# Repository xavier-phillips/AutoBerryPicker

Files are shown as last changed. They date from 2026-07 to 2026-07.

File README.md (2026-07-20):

<div align="center">

# AutoBerryPicker

**An autonomous, low-cost robotic arm that optically detects and picks strawberries, built as a VCE Systems Engineering Unit 3 & 4 folio project.**

Xavier Phillips, Viewbank College

  

   

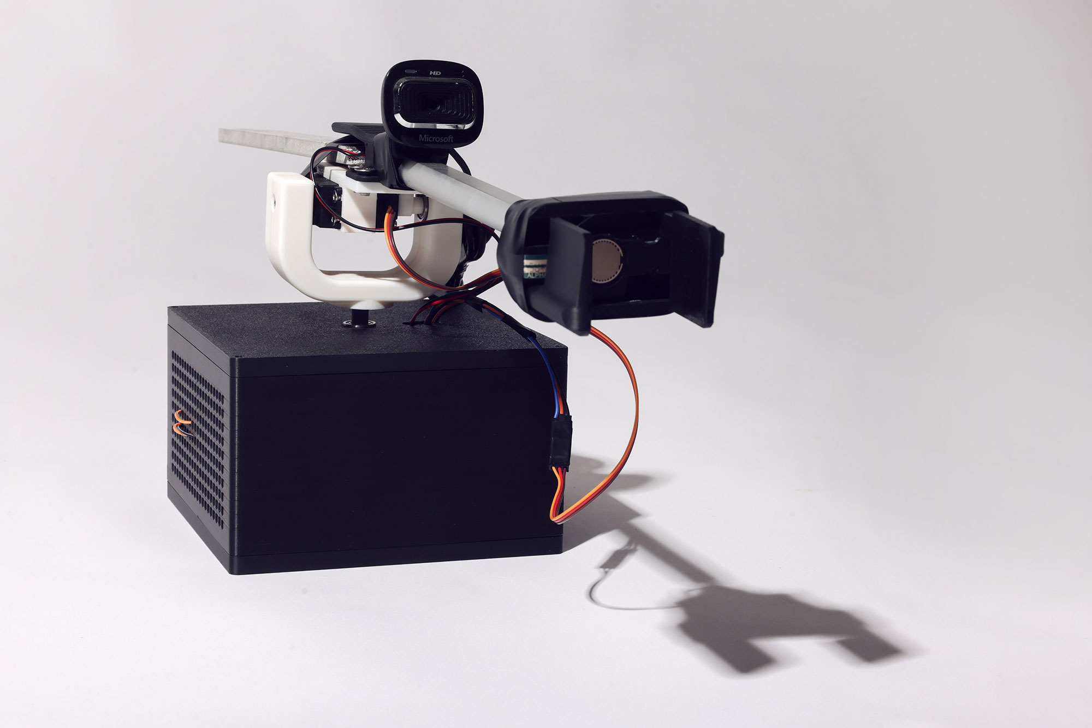
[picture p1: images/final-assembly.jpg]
Completed AutoBerryPicker assembly

_The completed AutoBerryPicker device. Top Designs 2026 / Source: Courtesy of the Victorian Curriculum and Assessment Authority. / Photo: Nicole Cleary_

</div>

---

## Contents

- [Overview](#overview)
- [Project Snapshot](#project-snapshot)
- [Technical Skills](#technical-skills)
- [Design Brief](#design-brief)
- [Design Process](#design-process)
- [Planning](#planning)
- [Development Log](#development-log)
- [Testing & Results](#testing--results)
- [Evaluation & Improvements](#evaluation--improvements)
- [Reflection](#reflection)
- [Gallery](#gallery)
- [Documentation](#documentation)
- [Acknowledgements & License](#acknowledgements--license)

---

## Overview

I built this robotic arm for my VCE Systems Engineering project to explore automation in agriculture, inspired by the United Nations' Sustainable Development Goal (SDG) #8: "Decent Work and Economic Growth". Specifically, Target 8.7 aims to eradicate forced labour and end modern slavery, including child labour.

[Statistics indicate](https://www.dol.gov/agencies/ilab/resources/reports/child-labor/findings) that the most common industry exploiting child and forced labour is the agricultural sector, where laborers are often used to pick small crops like cotton and berries.

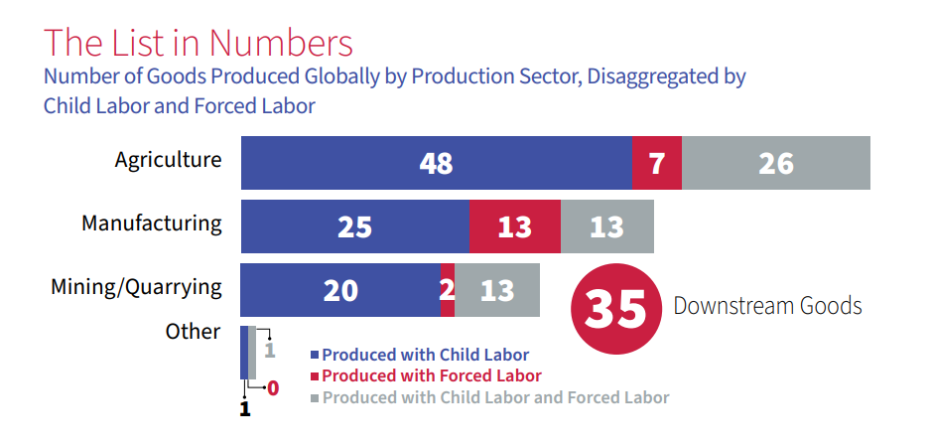
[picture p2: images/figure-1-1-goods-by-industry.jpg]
Proportion of goods produced by children and forced labour by industry

_Proportion of goods produced by children and forced labour by industry._

The issue can be alleviated by implementing automated robotic arms in farming areas. By creating an affordable robotic arm that can optically detect crops and carefully remove them from plants, such devices could replace children and forced labourers without reducing crop yield or efficiency. Food wastage may also be reduced by reducing the amount of bruised or damaged crops due to mishandling, thus supporting the UN's SDG 12.

The project design process utilised CAD software (Onshape) to precisely design components, fabricated with 3D printing additive manufacturing technology. The electromechanical system features an optical camera sensor and a custom program to identify strawberries in real-time and record their position; a microcontroller and motor controller relay this position to a robotic arm, which moves to the strawberry and precisely grips and removes the crop from the plant.

The project focuses on picking strawberries specifically, as they are fragile berries that can be used to demonstrate the robotic arm's ability to pick delicate crops precisely, without bruising them. If the device is capable of picking strawberries, it can be easily adapted to pick other crops, such as other types of berries or even cotton.

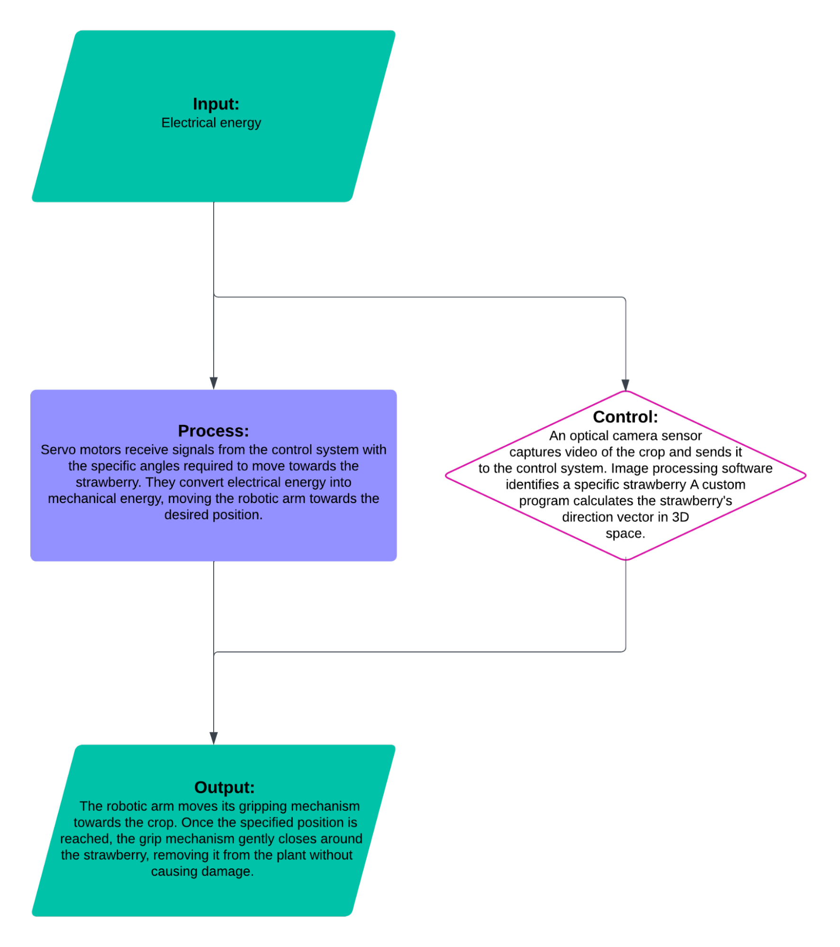
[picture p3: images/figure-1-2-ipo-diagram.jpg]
IPO diagram of the AutoBerryPicker device

_IPO diagram of the features of the AutoBerryPicker device._

<details>
<summary><strong>Glossary</strong></summary>

| Term | Meaning |
| --- | --- |
| **Device** | The complete, functioning electromechanical system |
| **User** | An individual or organisation implementing the device in a farm, workplace, or other agricultural setting |
| **FSR** | Force-sensing resistor |

</details>

---

## Project Snapshot

### Details

| | |
| --- | --- |
| **Course** | VCAA Systems Engineering, Units 3 & 4 (2025) |
| **Institution** | Viewbank College |
| **Developer** | Xavier Phillips |
| **Timeline** | 15-week development cycle |
| **Budget** | \$150 AUD |
| **Final Score** | 29/40 (73%) |
| **Core stack** | Onshape (CAD); Arduino IDE; Python (OpenCV, NumPy); Raspberry Pi 3; Arduino Uno R3 |
| **Manufacturing** | FDM 3D printing (Bambu Lab P1S / X1C); CNC laser engraving |

### Specifications

| Spec | Value |
| --- | --- |
| Degrees of freedom | 3 (polar/spherical configuration) |
| Power supply | 12V DC (battery or mains-rectified) |
| Max. power draw (theoretical) | 41.2 W |
| Weight (excl. power source) | 1081.4 g measured (976 g expected)  |
| Strawberry recognition accuracy | 0% false positives (16 trials) |
| Measured picking rate | 2.1 picks/min |
| Measured arm movement time | 2.07 s ± 0.13 s |

---

## Technical Skills

| Area | Skills and tools |
| --- | --- |
| Mechanical design | CAD modelling and mechanical design in Onshape |
| Embedded systems | Arduino Uno R3, Arduino IDE, embedded programming |
| Computer vision | Python, OpenCV, NumPy, real-time strawberry detection |
| Digital fabrication  | FDM 3D printing, CNC laser engraving |
| Electronics | Circuit design, power and current calculations, soldering, wiring, heat-shrink insulation |
| Testing and analysis | Diagnostic testing, statistical analysis, confidence intervals, two-tailed significance testing |
| Project management | Risk assessment, OH&S documentation, Gantt charts, timeline planning |
| Documentation | Technical documentation and evidence-based design evaluation |

<details>
<summary>Technical details</summary>

- Designed and modelled mechanical components using Onshape CAD.
- Programmed an Arduino Uno R3 using the Arduino IDE for embedded system control.
- Developed a computer vision system using Python, OpenCV, and NumPy for real-time strawberry detection.
- Manufactured prototypes using FDM 3D printing (Bambu Lab P1S and X1C) and CNC laser engraving.
- Designed and assembled electronic circuits, including power and current calculations, soldering, wiring, and heat-shrink insulation.
- Developed diagnostic tests and analysed results using statistical methods, including confidence intervals and two-tailed significance testing.
- Managed project planning through risk assessments, OH&S documentation, Gantt charts, and timeline tracking.
- Produced technical documentation and evaluated the final design using evidence-based analysis.

</details>

---

## Design Brief

The project's goal, an affordable electromechanical system to reduce worldwide reliance on unethical labour practices for crop harvesting, was governed by a strict set of constraints:

| Constraint | Why It Matters |
| --- | --- |
| Budget limited to **$150** | Ensures the device is affordable, as the cost of the final product influences its potential as a valid replacement for child labour and forced labour in the agriculture industry |
| Single developer | Limits complexity; simplicity must be prioritised to ensure realistic completion |
| **12V DC** power supply or battery | Ensures flexibility in where and how the device is used |
| Weight (excl. power source) **< 5 kg** | Ensures portability and compatibility with many mounting systems, including moving vehicles |
| Pick **≥ 5 strawberries/minute** | Based on the average weight of [12-15kg of strawberries picked per hour by workers](https://wikifarmer.com/); assuming 4 robots replace 1 human worker, a required picking rate of 5 per minute was determined |
| Max power draw of **24 watts** | Improves compatibility with mobile power sources such as a common 12V 2A portable battery |
| No safety risk to nearby individuals, users, or the environment | All moving parts and circuits must be enclosed to prevent accidental injuries from the mechanism or electrical shock |

<details>
<summary><strong>Full arm, control system & grip mechanism requirements</strong></summary>

**The robotic arm must:**

- Have three degrees of freedom, allowing it to move to any position in 3D space within a predetermined spherical radius while its base is in a fixed position
- Have a spherical range radius large enough to reach more than one plant without moving the base
- Have motors with sufficient torque to support the mechanism itself, and any additional load exerted when picking the crops
- Have motors with an appropriate RPM and acceleration to allow the picking of several strawberries per minute
- Have a base which can be secured easily with bolts or screws, allowing it to be mounted wherever the user desires
- Have a sturdy construction using a light material, and a full plastic shell to enclose wiring

**The control system must:**

- Have the capability to recognise strawberries in real-time
- Be able to extrapolate or estimate the relative position of a strawberry in 3D space based on a video camera feed and other sensors, in real-time
- Be able to calculate the angles of the servo motors to reach the desired 3D position to pick a strawberry, in real time
- Be compatible with open-source platforms such as Arduino IDE and Python

**The grip mechanism must:**

- Be able to evenly apply force to remove a strawberry from a strawberry plant without any bruising
- Be able to remove strawberries from strawberry plants, using as much force as required

</details>

<details>
<summary><strong>Design considerations explored</strong></summary>

- Increasing battery life using renewable energy sources like solar panels, adhering to Cradle to Cradle (C2C) standards
- Sustainably sourced materials that adhere to C2C standards
- The ability to manually select which crop the device should pick
- A trough for depositing picked crops into, separated based on crop type
- A secondary grip mechanism to hold onto the stalk while the crop is picked
- A modular belt conveyor system to transport harvested materials to an industrial storage area
- Wheels or tracks to provide an additional two degrees of freedom
- Remote monitoring and control via radio signals, Bluetooth, or Wi-Fi
- Regenerative braking circuits for the servo motors to reduce net energy consumption
- A user-friendly web or mobile interface for configuration of settings
- Easily accessible and replaceable internal/external components, requiring no specialised tools
- A manual or set of guidelines to help users operate the device

</details>

---

## Design Process

### Benchmarking Against Similar Products

| Product | Similarities | Differences |
| --- | --- | --- |
| Large robotic arm for vertical commercial strawberry farms (StrawberryPlants.org, 2023) | Articulated robotic arm; 2-finger robotic grip; only picks ripe crops; picks crops from a bottom-up angle | Optimised for vertical farms; primarily metal-based; moves autonomously using wheels; linear movement to pick crops |
| Large fixed robotic arm for cotton picking (Green Robot Machinery, 2022) | Optimised for traditional farms | Spherical robotic arm; only picks cotton using a vacuum; primarily metal-based; fixed base; picks from a top-down angle |
| Automatic strawberry picker (Octinion, 2017) | Articulated robotic arm; 2-finger robotic grip; only picks ripe crops; uses rotational movement; grips using a large surface area (cupped grip); picks from bottom-up angle | Optimised for vertical farms; automatically sorts bruised/diseased crops; primarily metal-based; moves autonomously using wheels |
| Cotton-harvesting autonomous platform (Maja et al., 2021) | Optimised for traditional farms; 2-finger robotic grip; uses linear movement | Cartesian robotic arm; only picks cotton; primarily metal-based; moves autonomously using wheels; picks from top-down angle; relies on pre-programmed map route and GPS |

_Overall summary of observations from research of various similar products._

The Octinion strawberry picker brought useful inspiration for how to carefully remove delicate crops from plants without bruising or damaging the crop. The device uses a rotating motion to remove strawberries and hold them in a cup-shaped holder, and the large surface area of the holder minimises pressure on the strawberry, reducing the risk of bruising and damage.

### Robotic Arm Type Selection

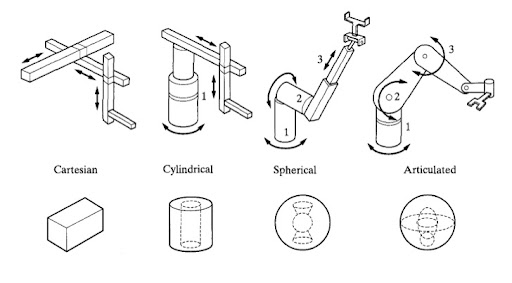
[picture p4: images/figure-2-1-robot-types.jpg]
Illustration of the 4 main robot types evaluated

_Illustration of the 4 main robot types that were evaluated._

| Type | Verdict |
| --- | --- |
| Cartesian Robot | Offers high precision and rapid acceleration but lacks range, requiring far more materials and larger size; deemed unsuitable |
| Cylindrical Robot | Simple coordinate system and construction, cheap and easy to program, but lacks flexibility for delicate, organic shapes; deemed unsuitable |
| **Polar (Spherical) Robot** | Uses a rotary actuator for elevation and a single linear actuator as the final degree of freedom that extends and retracts. **Selected.** |
| Articulated Robot | Can approach a point from various angles and navigate hard-to-reach areas, but requires more complex 3D position determination; considered but not selected |

> **Selected design rationale:** the polar robot approach was selected, as it offers sufficient range and flexibility while having a lower cost, software complexity, and hardware complexity. The control subsystem maps each camera pixel to a direction vector, and the device aligns itself in the rotational (base) axis and the elevational axis to point towards a direction vector at the centre of a crop. The radial (extension) axis extends using a linear actuator until it reaches a crop, using a button or touch sensor to detect contact. Once reached, the grip mechanism performs a grip action, and the radial axis retracts, removing the crop from the plant.

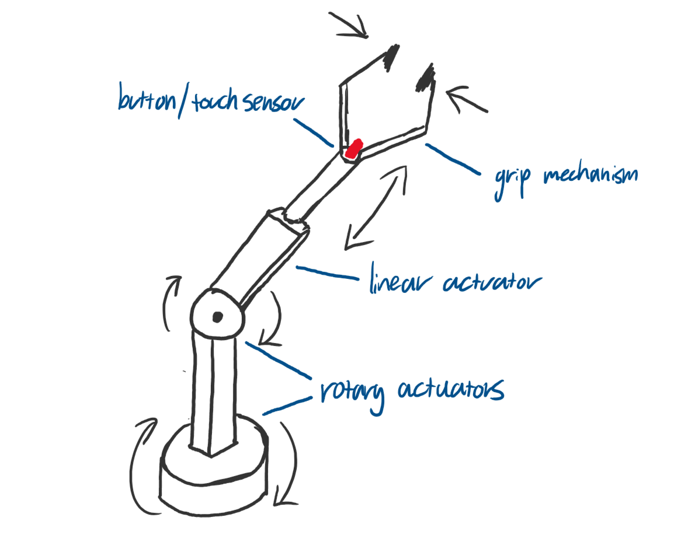
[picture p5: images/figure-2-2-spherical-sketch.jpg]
Sketch of the device in spherical configuration

_Sketch of the device in spherical configuration, including the three potential movement axes, and the touch sensor on the grip mechanism._

### Actuation, Sensing & Materials

<details open>
<summary><strong>Motor & actuator selection</strong></summary>

The DC electric linear actuator was selected over a servo linear actuator, primarily due to its cost-effectiveness, flexibility, and potential stroke length. Torque calculations for the elevational axis (modelled as a class 1 lever in Desmos, using a counterweight to counter gravity) informed the selection of MG996R servo motors for the rotational and elevational axes, providing adequate torque and precision for the lightweight configuration.

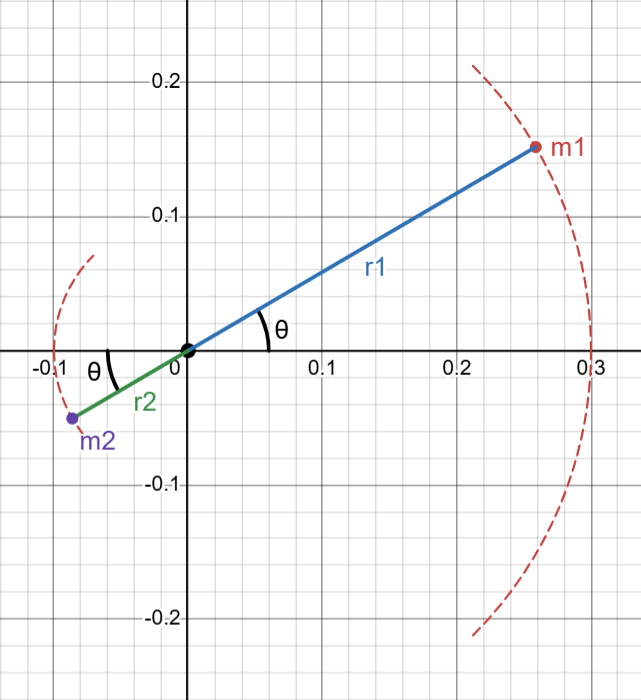
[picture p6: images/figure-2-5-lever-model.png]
Mathematical model of the arm as a 1st class lever

_Mathematical model of the arm as a 1st class lever in Desmos graphing calculator._

</details>

<details>
<summary><strong>Position determination & sensing</strong></summary>

A single camera and contact sensor setup was selected, rather than a complex stereoscopic system, reducing programming complexity and component cost while offering higher precision through direct physical feedback. The primary contact sensor is a Force-Sensing Resistor (FSR), chosen for its high sensitivity and low actuation force, ideal for detecting contact with a delicate strawberry. To prevent false positives from leaves, this is paired with a colour sensor with a built-in LED, helping to ensure the object is red and ripe before the grip sequence is initiated.

</details>

<details>
<summary><strong>Materials selection</strong></summary>

| Component | Options considered | Decision |
| --- | --- | --- |
| 3D printing filament | PLA vs Carbon Fibre Filament | **PLA**: cheaper for rapid prototyping and iteration, theoretically sufficient strength |
| Soft grip material | TPU flexible filament vs Sponge | **Sponge**: additional precision/durability not required for prototyping, easily cut and replaced |
| Base/frame | MDF panels vs alternatives | **MDF**: cheaper and easier to modify for mounting |

</details>

<details>
<summary><strong>Power & electronics</strong></summary>

A Raspberry Pi 3 performs real-time image analysis from the USB webcam, chosen for being compact and affordable while having sufficient processing power. It sends simple commands to an Arduino Uno R3, which serves as an intermediate controller for electronic components, while also sending FSR sensor and colour sensor data back to the Raspberry Pi. The Arduino was selected for being simple, reliable, and well-documented.

| Component | Max Current | Voltage | Power |
| --- | --- | --- | ----- |
| Colour sensor | 2mA | 5V | 10mW  |
| Linear actuator | 1A | 12V | 12W |
| MG996R (×2) | 2.5A | 5V | 12.5W |
| SG90 (grip) | 700mA | 5V | 3.5W  |
| Arduino Uno R3  | 50mA | 5V | 250mW |
| L298N | 36mA | 12V | 432mW |

_Maximum current, nominal voltage, and power draw of all electrical components._

In the worst-case scenario, the device draws a maximum of 41.2W, requiring the 12V power supply to supply at least 3.43A. Applying an industry-standard Factor of Safety of +125%, a requirement of 4.29A for the power supply was determined.

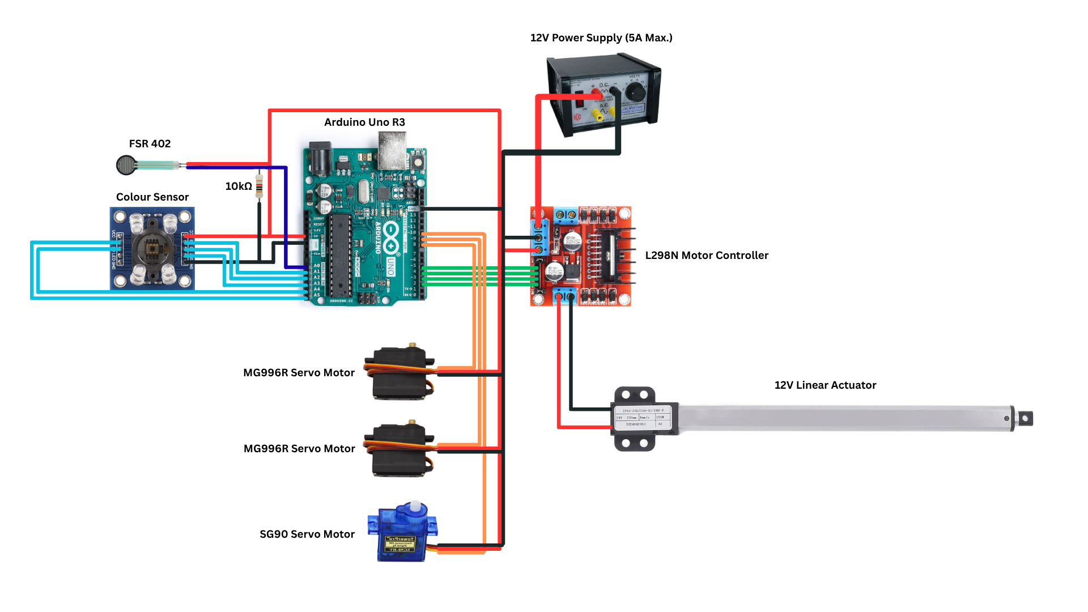
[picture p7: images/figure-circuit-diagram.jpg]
Circuit diagram of the AutoBerryPicker

_Figure: Circuit diagram of the AutoBerryPicker system._

</details>

### Final Design

The final design of the AutoBerryPicker balances range, flexibility, cost, and complexity. Because a heavy-duty linear actuator for the elevation axis would require torque far exceeding that of any affordable servo motors, I chose a lightweight 12V DC linear actuator for the extension axis. This enabled the use of MG996R servo motors for the rotational and elevational axes. Combined with a dual-sensor system, it formed an effective and affordable solution that met the original constraints.

---

## Planning

Tool and software selections were justified against alternatives:

| Tool / Software | Alternative(s) considered | Why it was chosen |
| --- | --- | --- |
| **Onshape** (CAD) | Autodesk Inventor | Cloud-based, automatic saving, allows work at school/home with no file transfer, infinite project history |
| **Arduino IDE** | PlatformIO | Simplicity, wide documentation, built-in example code snippets |
| **Python** (OpenCV, NumPy) | C++ | Simplicity and library availability: OpenCV for image processing/contour detection, NumPy for maths and GUI display |
| **VS Code** | Python IDLE, PyCharm | Efficient UX, multi-file project management, excellent debugging features |
| **3D printer** (Bambu Lab P1S & X1C) | CNC milling, manual fabrication | Custom/complex parts, precise small tolerances, high strength-to-weight ratio, fast printing enabled rapid, iterative prototyping |
| **CNC laser engraver** | 3D printing or ordering a base plate | High precision on 2D profiles, smoother/more accurate finish, higher speed |
| **Lego® bricks** | Cardboard mockups, skipping to CAD | Rapid, rough prototyping to test the mechanical idea of a polar robotic arm before investing time into CAD |
| **Electronics tools** (soldering iron, heat gun, hot melt glue gun) | Solderless breadboards, crimped connections | Reliable, durable electrical connections; reduced risk of failure due to tension on wires |
| **Diagnostic tools** (multimeter, DC power supply) | Guesswork, batteries for all testing | Essential for testing electronic components and finding faults |

A detailed work timeline plan, risk assessments, and a Gantt chart were completed to guide the 15-week production schedule.

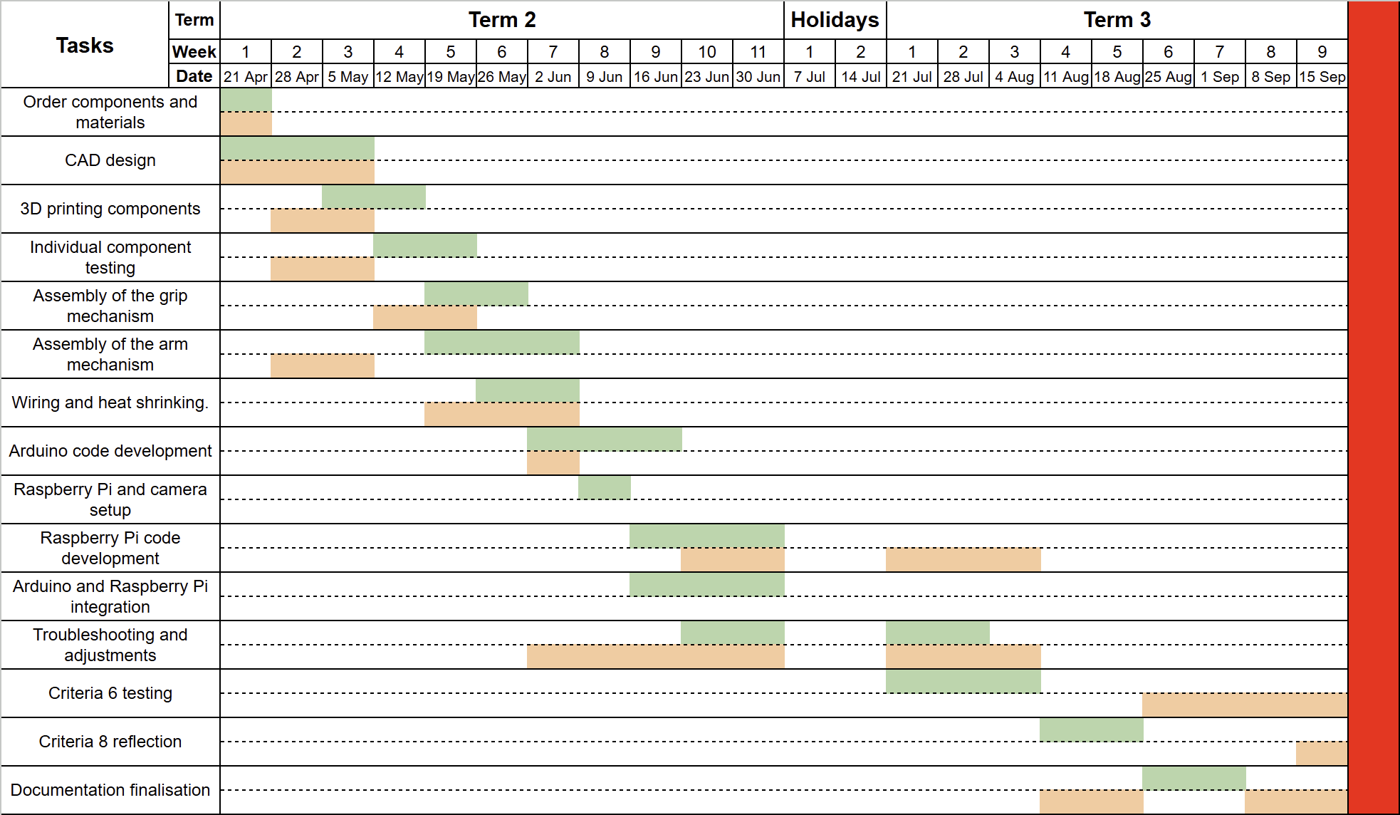
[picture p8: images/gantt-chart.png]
Gantt chart comparing planned vs actual timeline

_Planned (green) vs actual (orange) project timeline._

---

## Development Log

I developed the system over 15 weeks, following an iterative process where issues identified at the end of each session were addressed in the next. In Week 1, I built a rapid LEGO® prototype of the mechanical concept (base, rotational and elevational axes, linear axis, and grip mechanism) to gain a practical understanding of possible design challenges before committing to CAD and fabrication.

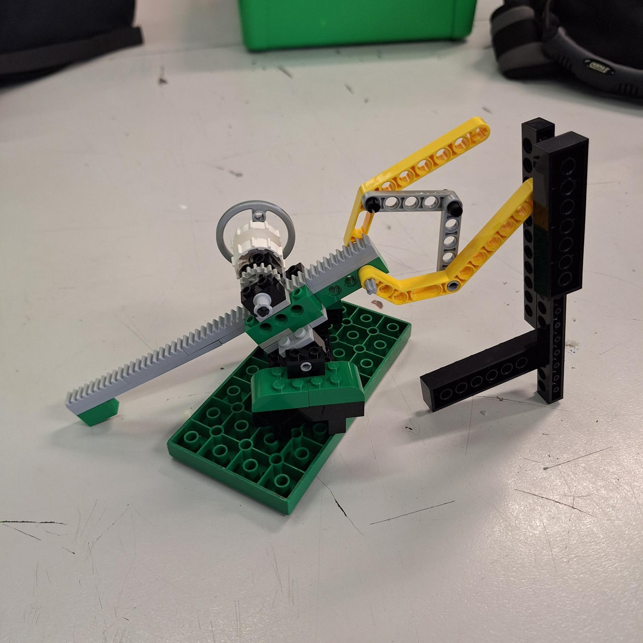
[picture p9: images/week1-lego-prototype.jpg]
LEGO prototype of the polar arm concept

_Early LEGO® prototype used to test the polar robotic arm concept._

The use of 3D printing technology was invaluable, allowing parts to be completely redesigned and reprinted within hours of identifying faults. Extensive daily logs documented the development, which proved useful for retrospectively clarifying past decisions and for evaluating repairability during later diagnostic testing.

> **Notable technical setbacks** encountered and resolved (or documented for future improvement) during the build:
>
> - A thin-walled central vertical shaft that snapped several times during development and was replaced, with friction ultimately proving insufficient to secure it to the rotational motor
> - A grip-mechanism load test in which the gears started to slip, leading to a critical failure and permanent damage to a servo motor from excessive torque load

| Week | Highlights |
| --- | --- |
| **1**  | Built a basic unpowered LEGO® prototype of the base, rotational and elevational axes, linear axis, and grip mechanism, to gain a practical understanding of possible challenges. Noted significant torque on the arm due to the weight of the grip mechanism and linear actuator, and realised it may be easier to have the entire motor move with the elevation mechanism, using the motor's own weight as a counterweight. Ordered components from Amazon and Core Electronics, sourced others from Viewbank College, and began CAD modelling of the circuit box in Onshape. |
| **2**  | The first iteration of the circuit box base was successful, with all parts and 3D printed standoffs fitting well. Found some flaws in the design and addressed them with hand tools and modifications in CAD. Successfully tested a new variation of the code with a draft polar coordinate system for easier control interfacing. |
| **3**  | The polar coordinate program test was successful, and test fitting gave a good demonstration of the range of the arm and showed the fit was secure. The main components of the arm were assembled without issue, and required components for the grip mechanism were sourced. |
| **4**  | With the majority of CAD work done, work moved to 3D printing the grip mechanism parts and assembling them. Became slightly behind schedule due to time spent catching up on documentation. Decided to use a pre-made gripper design (credit to Techniccontroller), and added a hole in the grip mechanism for a bolt to secure it to the linear actuator. |
| **5**  | With all electrical components in place, work began on finishing the wiring and closing the circuit box. The FSR was found to be functioning correctly. Heat-shrunk cable bundles and did cable management and soldering. |
| **6**  | Wiring and heat shrinking were completed, and the wiring pins of the motors were verified. Code and testing gave insights into how to program the arm to move, and verified that the motors and actuators in the arm work correctly. The circuit box was closed successfully with no issues, on track to begin software development: manual control first, then automatic optical detection with FSR feedback, before porting to the Raspberry Pi for full autonomy. |
| **7**  | Testing discovered critical flaws in the design along with hardware faults, including a damaged MG996R servo motor with sheared gears, which was removed for replacement. Redesigned the 3D printed components of the elevational axis to reduce loads and torques, including adding a counterweight, redesigned the actuator mount for improved strength, and redesigned the rotational base to be two-sided with an axle to improve strength and reduce flex. |
| **8**  | Progress on the new actuator mount and new MG996R motor allowed the elevation axis mechanism to be reassembled and testing resumed. Uncovered several issues with the modifications made to the rotational base and actuator mount, fixed them in CAD, and moved to a third iteration of both parts: filing counterweight pegs, reducing the elevational motor shaft diameter, strengthening axle supports, and adding an M3 bolt to secure the elevational motor. The rotating assembly was reassembled successfully with no apparent issues. |
| **9**  | Filed down the aluminium counterweight to allow it to fit. Completed the main mechanical and electrical components with no serious issues, and testing went well, manually moving the device into various positions and picking up and moving a foam block. Due to time constraints, decided to remove the FSR object-collision-detection feature and instead rely on strawberries being pushed along by the grip mechanism. |
| **10** | Implemented automated colour masking and boundary boxes for the detection of colours, laying the foundation of the software, and secured the counterweight and camera for more consistent performance. More progress than planned was made on user interface upgrades, and the program draft was ready for testing. Identified an issue with the Python GUI freezing, preventing progress towards automation. |
| **11** | A motor controller failure was only a minor setback: the cause of the actuator not moving was quickly identified and a replacement installed. Another minor setback with an unexpected modification was again quickly resolved. Decided to use a PID program as the guidance for the control subsystem, and gained a good grasp of the concept, with the next step being to create the OpenCV colour masking system to determine positional error. |
| **12** | Solid progress was made on an HSV Tuner program to find the optimal HSV settings for detecting red objects, which worked without issue and impressively distinguished red objects from the background, though detection failed at some angles when not directly lit. A wrap-around HSV system was trialled but ultimately showed no real improvement, so the design reverted to a simple HSV range, since strawberries are almost axially symmetrical and look similar from all angles. |
| **13** | Created a Red Foam Block to allow testing of the PID system. The main work on the PID code was completed, and a test of the new PID control program was successful, with the arm able to track moving red objects and centre itself on stationary ones. Decided to start with a PD controller first, excluding the Integral term and using only the x-axis, and made GUI updates for adjustable center sliders. |
| **14** | Added y-axis PID control to allow elevational movement. The new version with all axes implemented worked well and was able to successfully navigate to targets in 3D space, though oscillations were observed in the horizontal (rotational) axis. Testing of different PID settings provided valuable data on effective settings to reduce these oscillations and improve picking efficiency, precision, and accuracy. |
| **15** | Added a centroid calculation and smoothing filter, using a weighted moving average for the coordinates of objects, for more stable and reliable tracking with less jitter. Added a feature to save and load PID settings via a JSON file system. The final test of the device was completed, and it was decided not to use the Raspberry Pi 3, sticking with the laptop for running code instead due to time constraints, prioritising the functionality of the device. |

<details>
<summary>Development Photos</summary>

Week 1: LEGO prototype and circuit box CAD
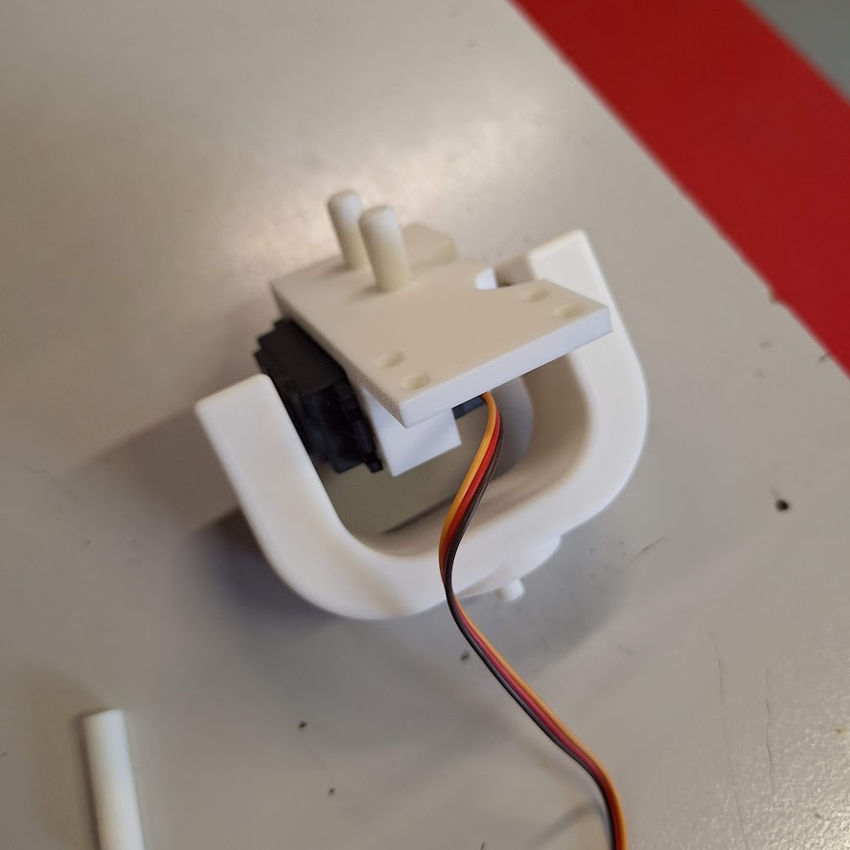
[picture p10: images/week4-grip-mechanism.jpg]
Week 4: grip mechanism assembly

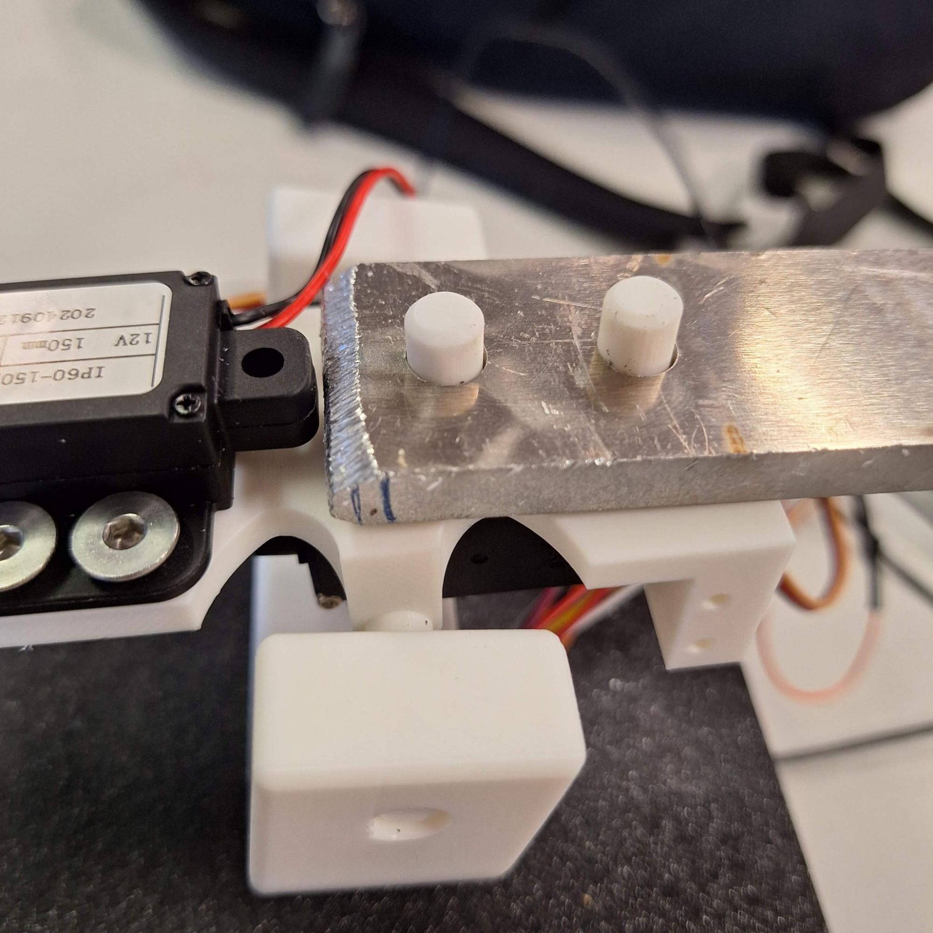
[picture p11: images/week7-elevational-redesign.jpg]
Week 7: redesigned elevational axis and counterweight

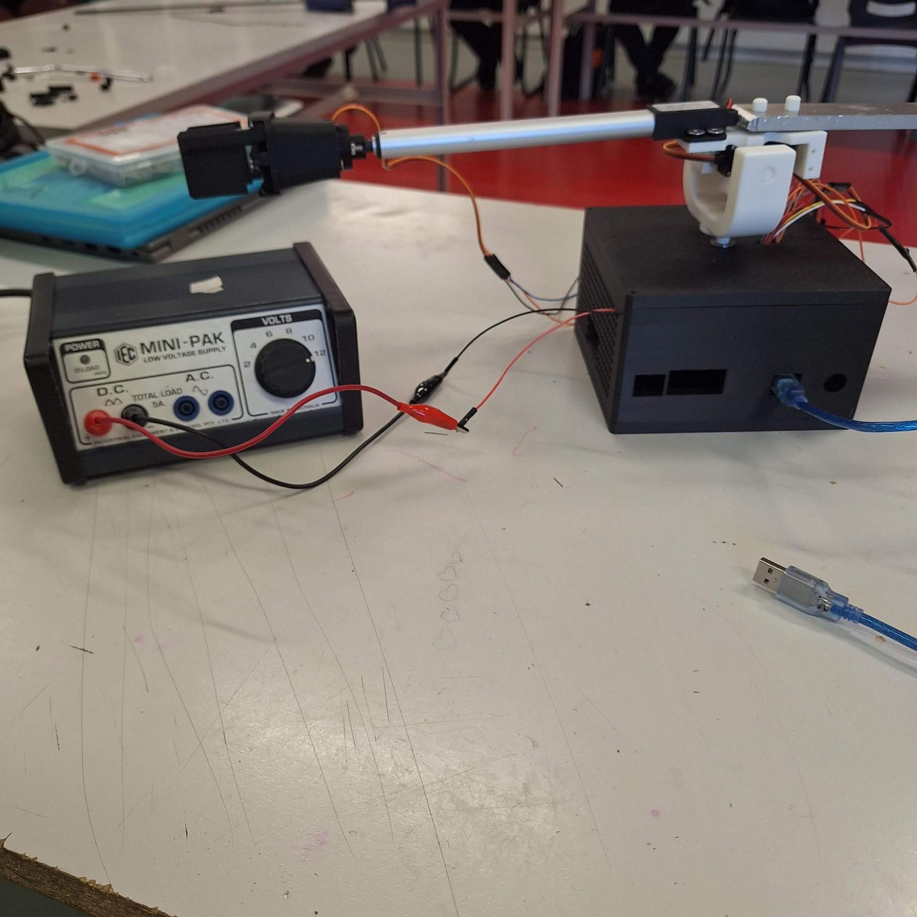
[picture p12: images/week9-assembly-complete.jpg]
Week 9: mechanical and electrical assembly complete

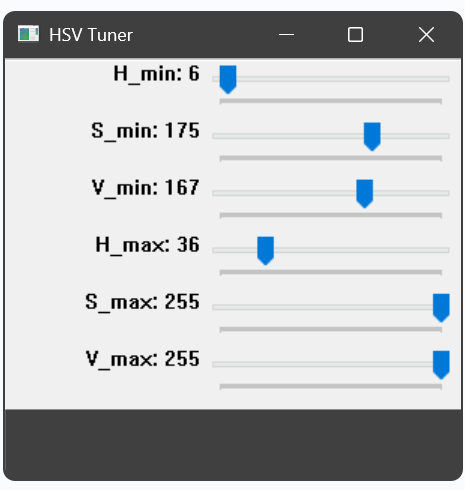
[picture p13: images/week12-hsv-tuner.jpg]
Week 12: HSV Tuner program in use

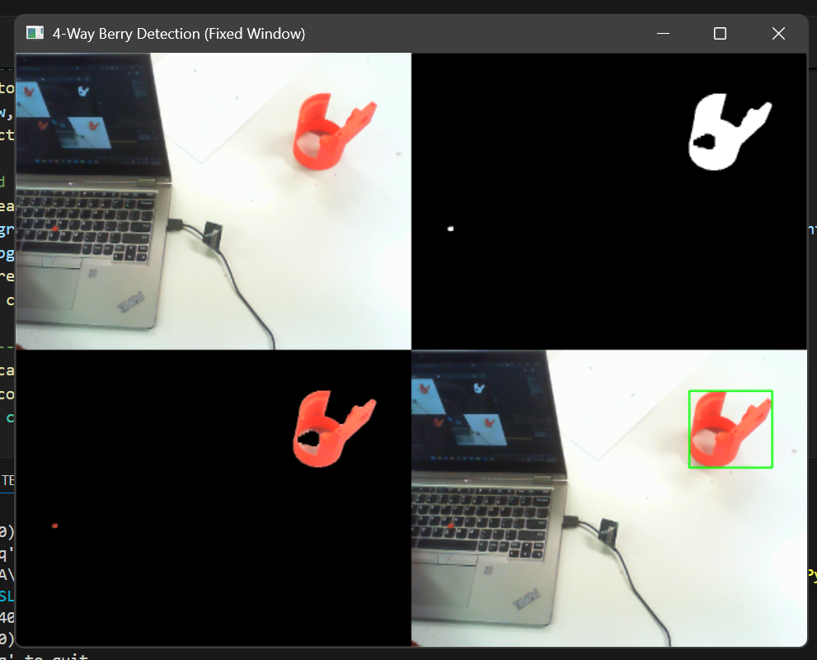
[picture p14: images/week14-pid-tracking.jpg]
Week 14: PID control tracking targets in 3D space


</details>

---

## Testing & Results

Ten diagnostic tests were conducted to evaluate the completed device against the design brief.

| # | Test | Aim | Result |
| --- | --- | --- | --- |
| 1 | Arm Range of Motion | Determine range of positions the arm can move to in 3D space | Rotational axis achieved only 52° (expected 180°, **-71%**), extension axis achieved 150mm (0.0% difference), elevational axis achieved 52° (+3.8%). Likely cause: poor attachment/skipping of the central vertical shaft |
| 2 | Arm Movement Speed | Determine time to move the arm between positions | Average of **2.07s** across 4 trials (95% CI: 1.94-2.20s), significantly less than the 3-second estimate |
| 3 | Torque and Stalls | Determine if MG996R motors avoid stalling under worst-case loads | Grip initially held over 500g, far exceeding expectations, but gears then slipped, causing a critical failure and permanent servo damage; test abandoned for safety and validity |
| 4 | Device Weight | Determine full weight excluding power source | **1081.4g** measured vs 976g expected, slightly higher, likely due to unmodelled wiring/bolts and non-uniform PLA wall density |
| 5 | Strawberry Recognition Accuracy | Determine false-positive rate when detecting strawberries among other crop types | **0% false positive rate** across 16 trials. HSV colour masking proved simple and effective |
| 6 | 3D Position Accuracy | Compare software-predicted position vs true position | Extension and elevational axes were within ~10% of commanded position (success); rotational axis differed significantly, likely due to gear slippage from an insecure vertical shaft |
| 7 | Strawberry Grip Test | Evaluate if the grip damages crops and holds them securely | No damage sustained to the strawberry, but grip force was weak and holding security was questionable |
| 8 | Picking Rate Efficiency | Assess detection-and-removal rate | **2.1 picks/minute** (142s for 5 objects) vs ~3/minute expected, limited by a damaged elevational motor and weak grip force causing slippage |
| 9 | Power Source Compatibility | Compare performance on 12V battery vs 12V DC supply | No statistically significant difference (p = 0.7583); device performance is unaffected by power source type |
| 10  | Power Consumption | Determine maximum power draw in operation | **30.5W** peak recorded (avg 28.0W) vs 41.2W theoretical maximum, likely due to the test power supply under-delivering voltage |

<details>
<summary>Test setup photos</summary>

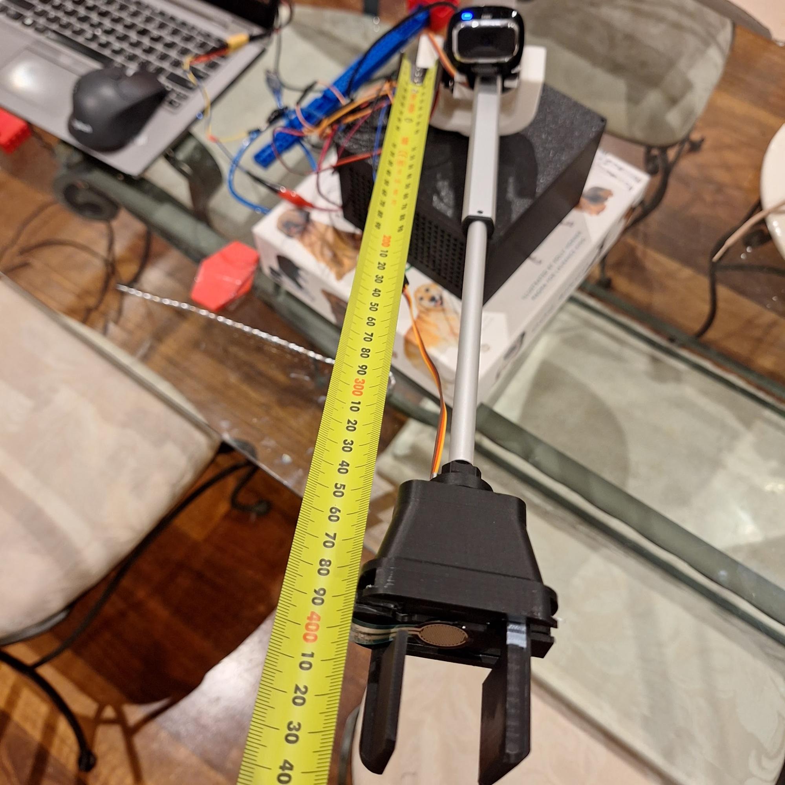
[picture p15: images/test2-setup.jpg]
Test setup for arm speed test

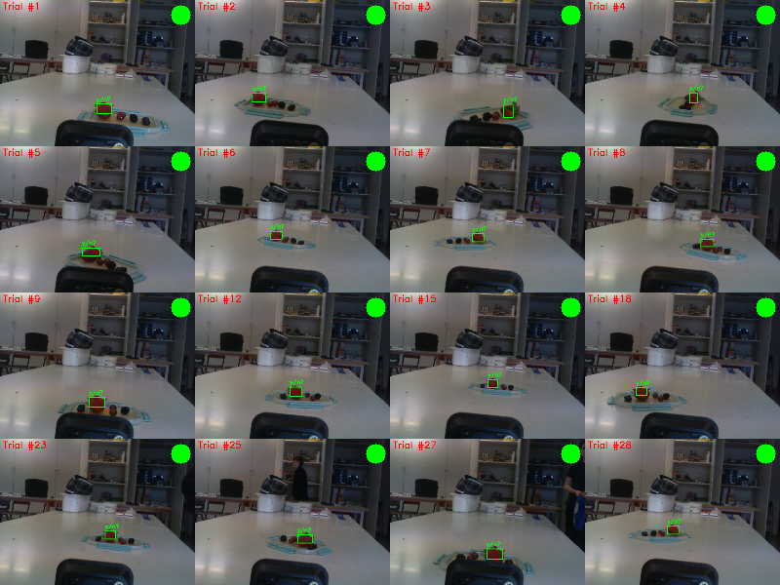
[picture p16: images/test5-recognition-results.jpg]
Results grid for strawberry recognition accuracy test

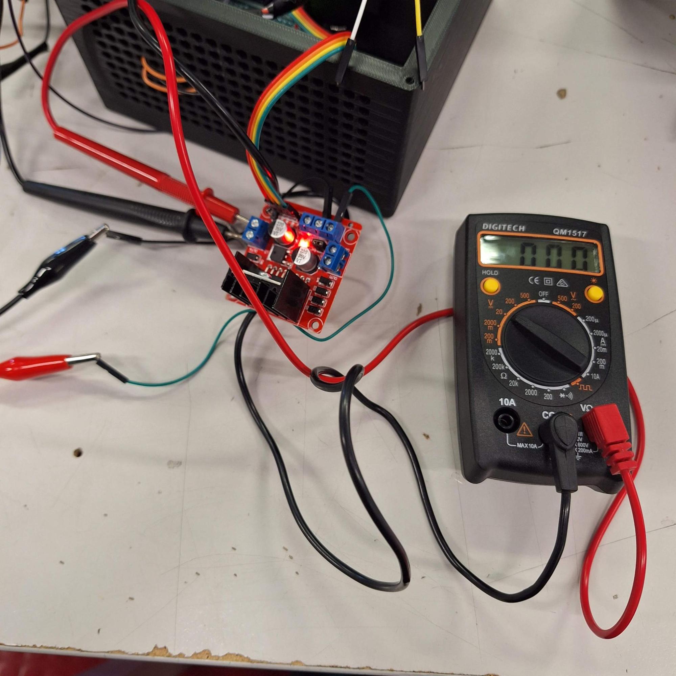
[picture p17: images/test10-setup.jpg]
Test setup for power consumption test


</details>

---

## Evaluation & Improvements

### Final Score: 29/40 (73%)

The final score was determined by evaluating 20 criteria on a scale of 0 to 2:

$$\text{Final Score} = \frac{1}{20 \times 2} \times \sum_{n=1}^{20} S(n) \times 100\%$$

### Project Cost

Most components were reused from old projects or supplied by Viewbank College. The total value below assumes an individual starts with no materials and wants to build one from scratch. All prices are the cheapest available at the time of writing.

| Component | Cost |
| --- | --- |
| Bambu Lab PLA Basic filament (0.455 kg) | \$9.10 |
| 12V Linear actuator (150 mm, 20 N) | \$36.10 |
| Bolts and nuts (<40 pcs used) | \$1.18 |
| Flanged ball bearings (×2) | \$6.95 |
| MG996R servo (×2) | \$17.56 |
| Microsoft Lifecam 3000 | \$39.95 |
| Arduino Uno R3 | \$19.99 |
| L298N motor controller | \$8.95 |
| SG90 micro servo | \$4.28 |
| Aluminium counterweight | \$5.04 |
| Jumper wires (<40 pcs) | \$7.27 |
| Heat shrink tubing (<10 pcs) | \$0.14 |
| Arduino-compatible colour sensor | N/A |
| Interlink FSR 402 | N/A |
| Raspberry Pi 3 | N/A |
| DPDT Latching Toggle Switch | N/A |
| 3 mm plywood board | N/A |
| Sponge (for grip padding) | N/A |
| **Total** | **\$156.51** _(vs. \$150 target)_ |

_Components marked N/A were sourced from school inventory or personal stock at no cost to the project budget._

During planning, overarching details such as torque calculations, power calculations, and arm types were extensively investigated and mathematically modelled. However, some details, such as CAD designs and code logic, were not finalised until production, and prototyping occurred later than ideal in the first week of production rather than during Criteria 2 decision-making. Several feature compromises were also made to meet the timeline, including the omission of the colour sensor and FSR position-determination systems, and the omission of the Raspberry Pi 3 (with reliance on a laptop for the Python program instead).

**What Went Well**

- The production stages were well-documented and executed, and the iterative development process, facilitated by 3D printing, was invaluable, allowing issues identified at the end of each session to be addressed in later logs
- The diagnostic testing and evaluation was successful overall, and gave a clear picture of device performance against the design brief
- With a final score of 73%, the system was ultimately successful in meeting the majority of the evaluation criteria from the design brief, resulting in an autonomous system able to grab and move strawberries

**What Could Be Improved**

- A major flaw identified was the slow speed of the device due to actuator and PID control limitations, which severely limits commercial viability for farm use, hindering the device's support of SDG 8
- The grip mechanism was not very effective at handling the variety of strawberry sizes, as it moves paddles by a fixed amount, squishing larger berries and failing to secure smaller ones
- Feature compromises (omitted colour sensor, FSR positioning, and Raspberry Pi 3) reduced the system's fidelity to the original design brief

> This indicated that the initial goals for the device's performance, including its considerations and constraints, may have been too ambitious. Still, working through those problems taught a lot over the course of the project.

### Recommendations for Improvement

<details>
<summary><strong>Planning recommendations</strong></summary>

1. Allocate more time to researching how to program the device, including pseudocode of the full device and specific software requirements
2. Research safety requirements to protect the device (not just the user), reducing the risk of catastrophic failures such as the 2 occasions of motors being destroyed by excessive torque loads
3. Complete physical prototypes earlier in planning to inform component and design selection
4. Fully complete design finalisation, including CAD modelling, in the planning stage

</details>

<details>
<summary><strong>Design recommendations</strong></summary>

1. Change from a polar robotic arm to an **articulated robotic arm** to improve load handling, range of motion, and versatility
2. Replace the single optical sensor with a **3D detection system** such as a stereoscopic camera set, to improve accuracy and facilitate inverse kinematics
3. Redesign the grip mechanism: either a deformable, compliant grip, or a rigid design with force sensors on each paddle
4. Implement a **dedicated power connector** (e.g. barrel jack DC connector) for easier, more commercially viable power sourcing
5. Reduce perforations in the circuit box to better handle humidity, dust, and rain in outdoor farmland
6. Rework code to handle **multiple strawberries** in the camera frame simultaneously

</details>

---

## Reflection

The AutoBerryPicker set out to show that an affordable, single-developer robotic system could offer a viable path toward reducing reliance on child and forced labour in agriculture. The final device, a polar-configuration robotic arm using a single camera, contact sensing, and servo/linear-actuator control, picked strawberries autonomously, achieved a 0% false-positive detection rate, and operated reliably across different 12V power sources.

At the same time, the project surfaced clear engineering trade-offs. Mechanical failure points such as the vertical shaft attachment limited range of motion and repeatability, and actuator speed constrained picking rate well below commercial viability. These findings, together with the recommendations above, point to a concrete path for the next iteration, from an articulated arm and 3D sensing to a force-adaptive grip, and are probably the most useful outcome of the project: a set of evidence-based lessons for future development.

---

## Gallery

<details>
<summary>Gallery GIFs</summary>

Robotic arm rotation axes
Robotic arm extension axis
Robotic arm grip axis
Robotic arm manual manipulation
Computer vision track-and-grab routine

</details>

---

## Documentation

The complete Systems Engineering folio (Criteria 1-8), including full risk assessments, the detailed 15-week development log, complete testing methodology, and reference list, is available in two parts:
- [Criteria 1-4](docs/AutoBerryPicker_Folio_Criteria_1-3.pdf)
- [Criteria 5-8](docs/AutoBerryPicker_Folio_Criteria_4-8.pdf)

---

## Acknowledgements & License

<details>
<summary><strong>Acknowledgements</strong></summary>

I would like to thank my Systems Engineering Units 1&2 teacher Veena Nair, and my Systems Engineering Units 3&4 teacher Luke Power-Virant, for their continual support and guidance throughout the development of the AutoBerryPicker and my Systems Engineering education at Viewbank College.

I would also like to acknowledge Edgar Welte, M. Sc., a PhD student in Robotics and Artificial Intelligence at the Karlsruhe Institute of Technology (KIT), for sharing the CAD design of the parallel gripper mechanism under the username Techniccontroller.

Furthermore, I would like to acknowledge David Payne from Banyule Nillumbik Tech School for his support in manufacturing the aluminium components using a waterjet cutter in 2024, as part of my previous year's folio, which were repurposed and incorporated into this project as counterweights.

I also acknowledge the support of Viewbank College's IT technicians Hai Yan and Danny Nguyen, whose assistance was crucial for setting up and maintaining the 3D printers in the J07 engineering workshop room.

</details>

## License

This project is licensed under the MIT License. See the [LICENSE](LICENSE) file for details.

---

<p align="center"><sub>Completed as part of the VCAA Systems Engineering study design at Viewbank College.</sub></p>

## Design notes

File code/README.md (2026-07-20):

# AutoBerryPicker - Code

The code is split between an Arduino program and a Python program. The Arduino controls the motors, actuator, and sensors, while the Python program handles the camera input, strawberry detection, and PID tracking.

The original plan was to run the Python program on a Raspberry Pi 3, but during the final build it was run from a laptop instead (refer to the main README and Week 15).

## Files
- `autoberrypicker-controller.ino` - Arduino code that controls the MG996R servos and linear actuator through the L298N motor driver. It also reads data from the FSR and colour sensors and receives position commands from the Python program.
- `autopicker_control.py` - Python program that handles webcam input, strawberry detection using HSV colour masking, PID control for x/y tracking, and the GUI used for adjusting HSV and PID settings. PID settings can also be saved and loaded using JSON.

## Running it

### Arduino
1. Open `autoberrypicker-controller.ino` in the Arduino IDE.
2. Select Arduino Uno R3 as the board.
3. Upload the code and connect the Arduino to the computer running the Python program through USB serial.

### Python
1. Install Python 3 and the required libraries:
```

pip install opencv-python numpy

```
2. Run `autopicker_control.py` with a USB webcam connected (a Microsoft LifeCam 3000 was used during testing).
3. Before running the main program, use the HSV Tuner to adjust the colour detection settings for the current lighting conditions.

## Note
This code was created for a VCE Systems Engineering folio project (Top Designs 2026 selection). It is not intended as a maintained software package.

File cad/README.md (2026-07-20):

<div align="center">

# AutoBerryPicker CAD Files

**3D models and manufacturing files for the electromechanical components of the AutoBerryPicker system.**

  

</div>

---

## Full Assembly

### [`autoberrypicker-full-assembly.step`](models/autoberrypicker-full-assembly.step)

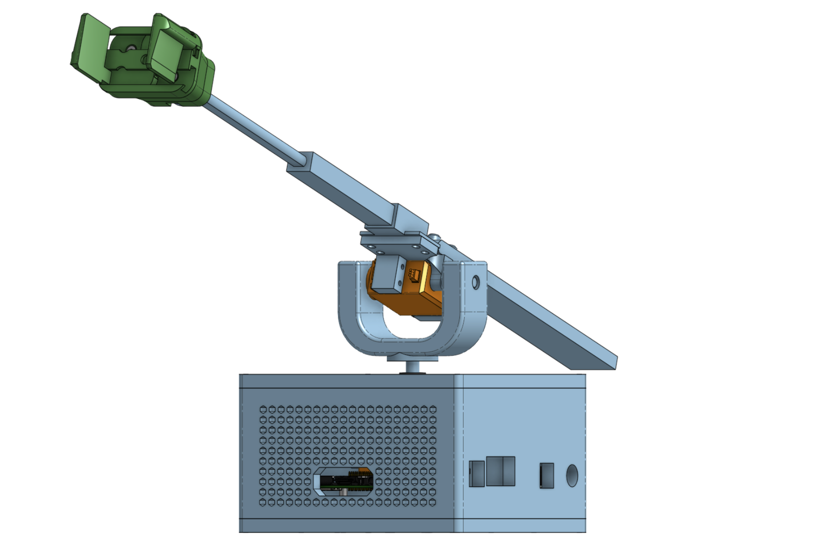
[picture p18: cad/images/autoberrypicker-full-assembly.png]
Full Assembly

_The complete AutoBerryPicker CAD assembly._

#### Explanation

The final design choice for the AutoBerryPicker is a result of a series of separate investigations and small choices, where each component choice was made to create a system that addresses the constraints of the design brief. This combination of a polar arm, lightweight actuators, servo control, and a dual-sensor system creates an integrated solution to the problem of picking berries autonomously.

#### Materials & Processes

The internal and external components of the system must all be easily accessible and replaceable without requiring any specialised tools or equipment. This improves the ease of maintenance and repair of the device and allows the user to replace damaged components.

---

## Circuit Enclosure

### [`circuit-box-base.step`](models/circuit-box-base.step)

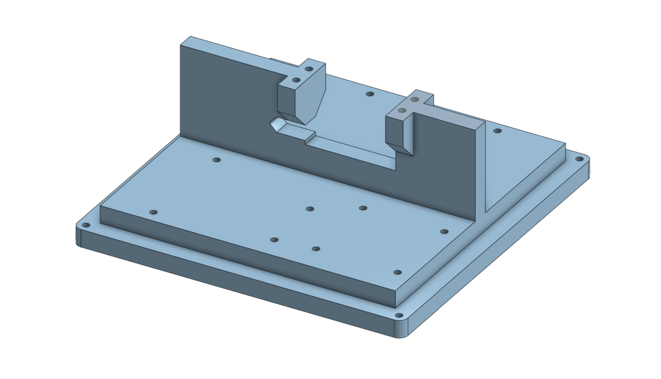
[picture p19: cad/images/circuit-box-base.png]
Circuit Box Base

_The base plate and mounting surface for the microcontrollers._

#### Explanation

This is the base of the circuit components box, where the Arduino, L298N, and Raspberry Pi will be mounted. This will ensure that the wiring between the various components stays intact, preventing any movement of components which could lead to shorted or broken circuits. Added barriers have been put in place to separate the 3 main microcontrollers. There is a slot in the base which tightly fits the motor, and includes four screw holes for secure mounting of the motor.

#### Modifications

I noticed that the barrier between the L298N and Arduino was in the way of wiring, and made it very difficult to plug things into the L298N. I decided to remove this wall by snapping it off. I also adjusted the 3D model in Onshape so that if I print a second version the flaw is addressed appropriately.

#### Materials & Processes

Due to the large size of the base, it was printed with 0.20mm layer height and utilised 6 wall layers for additional strength.

---

### [`circuit-box-walls.step`](models/circuit-box-walls.step)

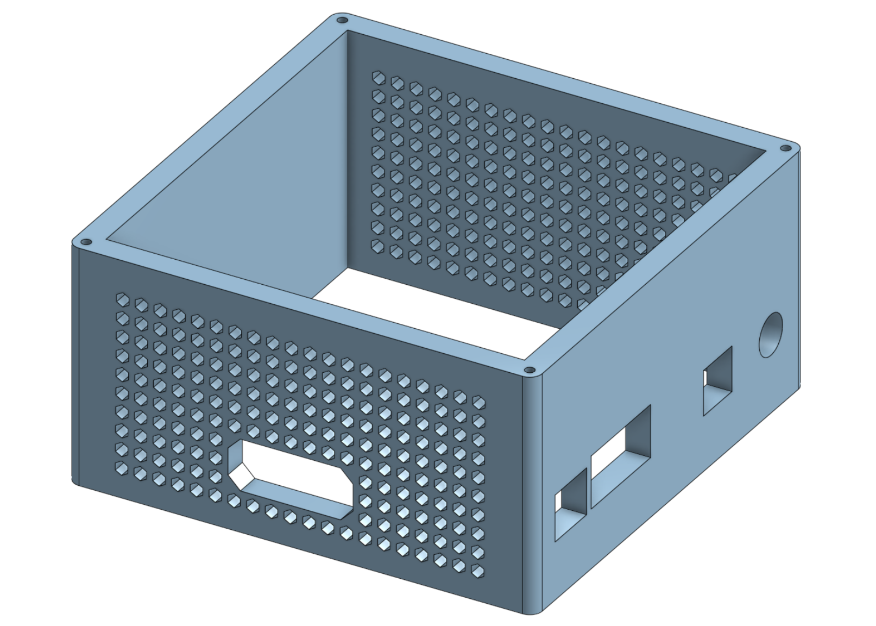
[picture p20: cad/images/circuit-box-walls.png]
Circuit Box Walls

_The ventilated walls of the circuitry enclosure._

#### Explanation

These are the walls of the circuitry box, which surround the wiring to prevent any broken or short circuits due to collisions or movement. They are designed to fit tightly on top of the base, and are 8mm thick to ensure long-term durability and resistance to external conditions. The hexagonal grille on two of the faces of the box serves two purposes; the first is to provide ventilation and reduce the risk of overheating due to the heat radiated by parts within the box. The second purpose of the grille is to allow the lights inside the box, including the Arduino Uno R3 and L298N power indicator lights, to be visible. I also included the addition of holes for wiring, including slots for USB cables and ethernet for the Raspberry Pi, and slots for power and a serial cable for the Arduino.

#### Modifications

When attempting to fit the circuit enclose walls, I encountered two main issues. The first main issue was that the slot for the HDMI cable became obstructed, which may hinder code development if I need a display output from the Raspberry Pi 3. The second issue was that the walls simply did not fit, as a plastic protrusion from the Raspberry Pi 3 (adjacent to the HDMI port) physically stopped the walls from slotting into the correct position.

I modified the Onshape CAD model with the issue addressed by creating a new hole in the side of the walls. I also cut a slot in the circuit box walls to allow for a Micro USB cable to be fed through for Raspberry Pi 3 power.

---

### [`circuit-box-lid.step`](models/circuit-box-lid.step)

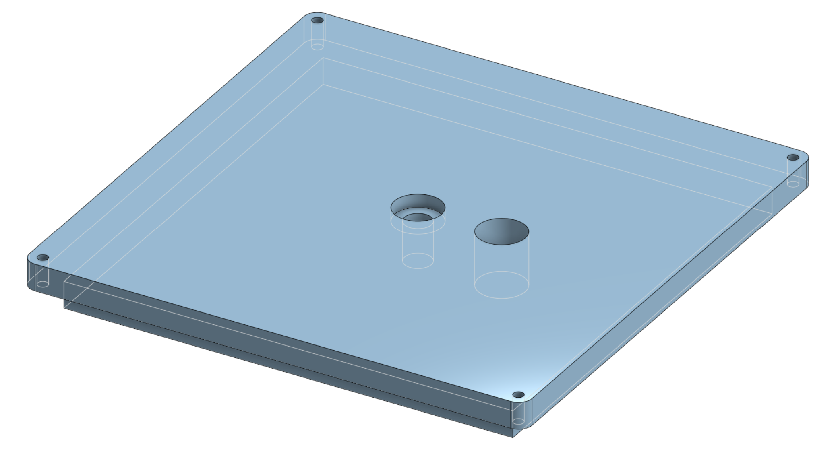
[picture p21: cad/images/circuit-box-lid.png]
Circuit Box Lid

_The lid of the circuit box, featuring the primary bearing indent._

#### Explanation

This is the lid of the circuit box, which is also 8mm thick and tightly slots on top of the walls. There is an indent that is designed to tightly fit the 14mm outer diameter ball bearing, providing more stability to the vertical shaft of the device by restricting sideways movement.

#### Modifications

I drilled a hole to allow for the routing of wiring from the elevational motor, linear actuator, and grip subsystem, as I neglected this in the original design. I also adjusted this in the CAD model on Onshape, except instead I added a larger, 14mm hole to provide additional space and mitigate risk of pinched wires and damage.

---

## Robotic Arm Subsystem

### [`vertical-shaft.step`](models/vertical-shaft.step)

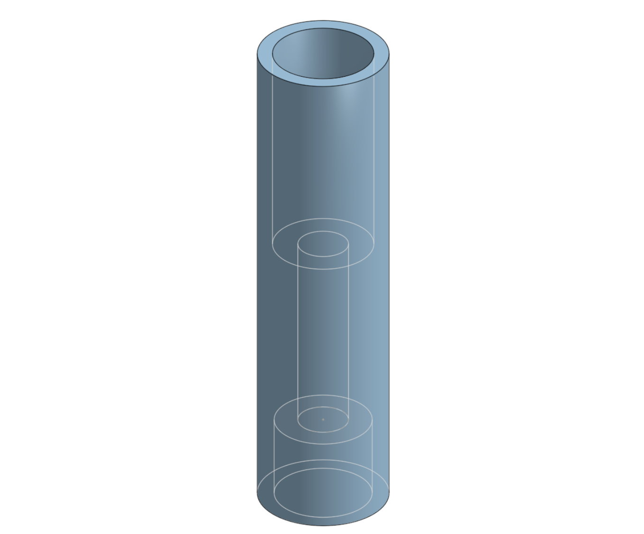
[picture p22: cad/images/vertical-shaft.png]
Vertical Shaft

_The primary drive shaft connecting the base motor to the rotational assembly._

#### Explanation

The shaft has an 8mm outer diameter to tightly fit the slot in the lid of the circuit box, and matches the diameter of the flanged bearing to ensure reduced friction and support from sideways loads. The shaft has a 5.8mm inner diameter to allow it to very tightly fit the pin for the rotational base and the MG996R motor spline. Furthermore, it has an M3-sized opening to allow it to be secured to the rotational motor if required.

#### Modifications

When moving the device back to a safe storage place, I accidentally knocked the mechanism on something, resulting in the 3D printed vertical shaft snapping. To fix this, I just printed another vertical shaft, as it was an issue with improper handling rather than a design issue.

The vertical shaft was thin-walled and broke several times during development; it may be a critical failure point. Furthermore, the attempt to use friction to secure the vertical shaft to the rotational motor may have been insufficient. The original plan was to use a bolt, however this was substituted as the bolt often failed to thread properly, and also made the device difficult to disassemble for maintenance. As a future improvement, a thicker and bolt-secured vertical shaft should be explored.

---

### [`rotational-base.step`](models/rotational-base.step)

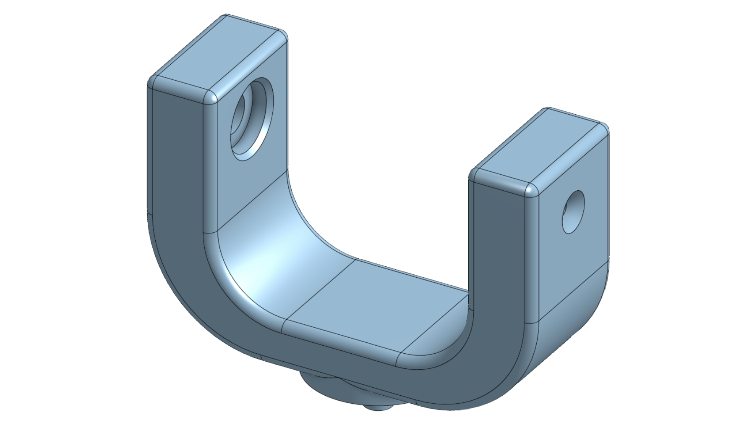
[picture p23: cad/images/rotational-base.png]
Rotational Base

_The two-sided rotational base component._

#### Explanation

This is the redesigned rotational base component. Instead of an asymmetrical design, I have switched to a symmetrical design. A 14mm hole is included for adding a flanged bearing to insert the axle I added on the linear actuator mount, reducing friction and improving the longevity and efficiency of the design.

#### Modifications

I redesigned the rotational base to be two-sided with an axle, to improve strength and reduce flex. Compared to the tight fit of the motor horn, the slot for the motor shaft in the rotational base part was far looser, preventing the motor from being able to produce any torque, as it would just slip in the slot.

To address this, I edited the CAD model in Onshape, reducing the diameter of the slot for the motor shaft from 6.0mm to 5.7mm, which should result in a tighter fit. I also added an M3 bolt to secure the elevational axis motor to the rotational base.

---

### [`linear-actuator-mount.step`](models/linear-actuator-mount.step)

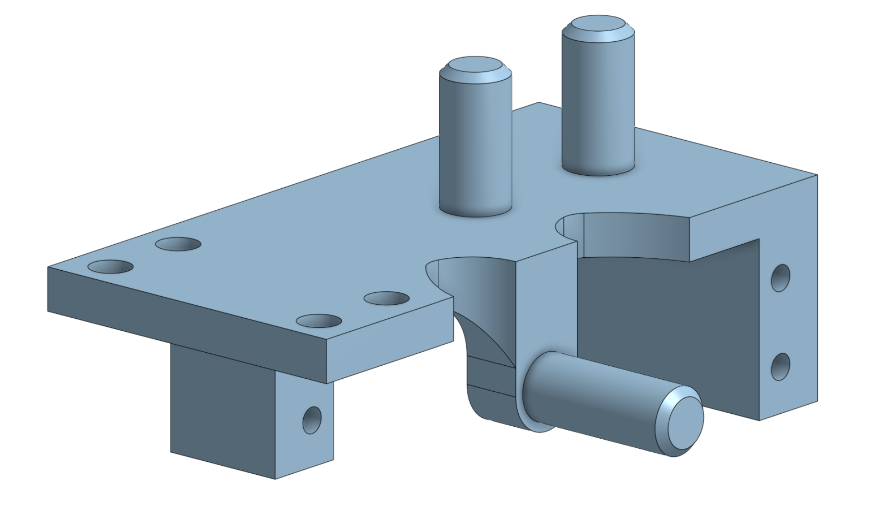
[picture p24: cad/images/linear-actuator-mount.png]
Linear Actuator Mount

_The mount connecting the linear actuator and counterweight to the elevational axis._

#### Explanation

This is the redesigned actuator mount. The first change to the design is an additional axle, so that the elevating components are supported symmetrically rather than just by the shaft of the motor. This reduces the radial load on the elevational axis motor. The second main change was the addition of two pegs, which allow metal counterweights to be attached. These counterweights create an opposing moment to the one generated by the linear actuator and grip mechanism, reducing the torque required to maintain equilibrium.

#### Modifications

After attempting to install the linear actuator mount onto the elevational servo motor, I realised that I didn’t consider adding a slot for the routing of wiring, so it didn’t fit. To fix this, I decided to remove a section of the part to allow it to fit.

The measurements for the diameter of the pegs were off by about 1mm, resulting in a peg that was too large to fit the holes in the aluminium. I used a rasp to remove PLA material from the pegs to reduce their diameter and improve the fit. I also edited the CAD model in Onshape, reducing the diameter from 8.7mm to 7.8mm for ease of manufacture if the part is to be re-printed.

The axle of the actuator mount originally snapped off the rest of the part. To address this structural integrity issue I will both increase the infill and wall loop count in print settings. I also edited the CAD model in Onshape, adding some fillets and chamfers to reduce the risk of snapping by reducing the number of right angles in the part.

#### Materials & Processes

The automatic support generation in the slicer placed supports in M3 screw holes, which were very difficult to remove from the part. Thus, I will instead use manually placed supports if I print the part again.

---

### [`grip-mechanism-mount.step`](models/grip-mechanism-mount.step)

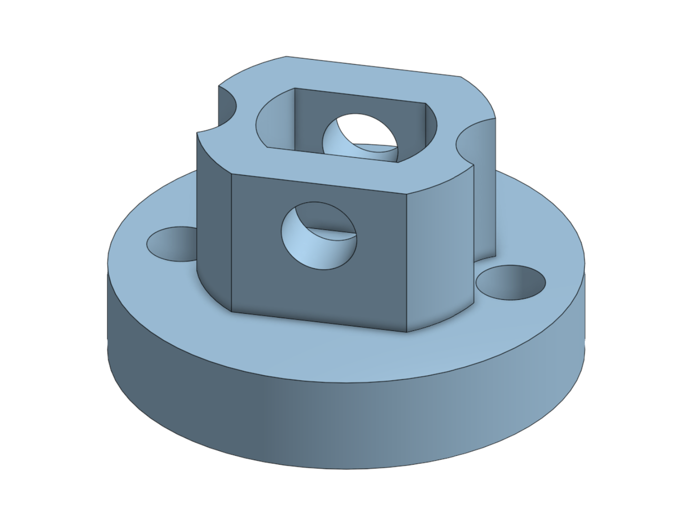
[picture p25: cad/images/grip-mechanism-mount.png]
Grip Mechanism Mount

_The structural mount for the micro servo parallel gripper._

#### Explanation

This is the design for the mount of the grip mechanism. It is designed to allow the grip mechanism to be mounted to the arm using two M3 bolts.

#### Modifications

After assembling the components of the grip mechanism, I realised that I hadn’t added a hole to secure the grip mechanism to the linear actuator. Without this, the grip would not be securely attached, so I modified the CAD model to add a 4mm hole.

---

### [`aluminium-counterweight.step`](models/aluminium-counterweight.step)

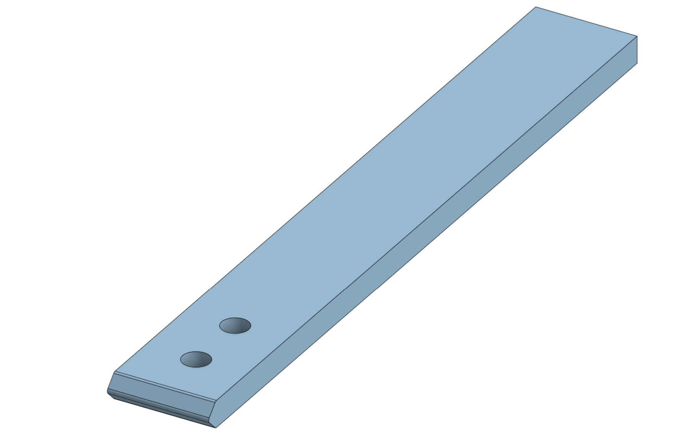
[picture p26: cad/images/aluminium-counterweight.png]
Aluminium Counterweight

_The machined aluminium plate used to counter-balance the linear actuator._

#### Explanation

This is an 8mm deep, 30mm wide aluminium plate. I plan to use this as a counterweight to reduce the required torque to maintain equilibrium for the device, reducing the risk of any damage to the servo motor and shearing of gears.

#### Modifications

After trying to put the counterweight onto the pegs, I noticed it wouldn’t fit, despite the pegs being a perfect match for the diameter of the holes in the aluminium this time. The reason it didn’t fit was that the counterweight slightly protruded past the linear actuator, so it would collide with the actuator and prevent proper insertion. To fix this, I used a rasp to shave away material from the aluminium plate, reducing its length slightly so that it was able to fit without any collision.

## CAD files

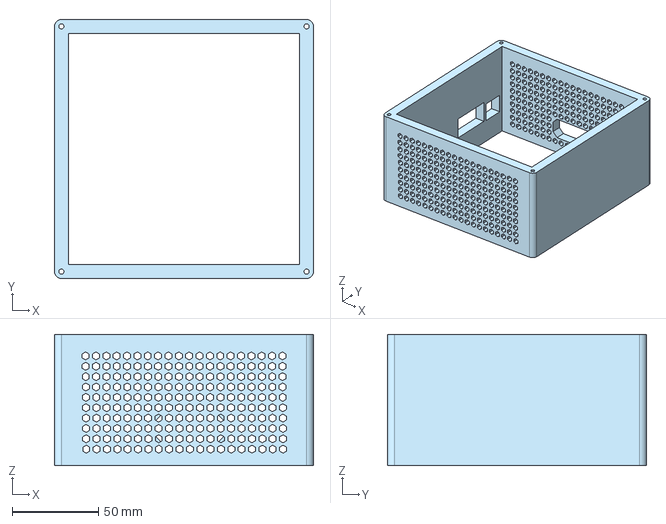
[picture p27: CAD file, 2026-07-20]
cad/models/circuit-box-walls.step
150.0 x 150.0 x 76.0 mm

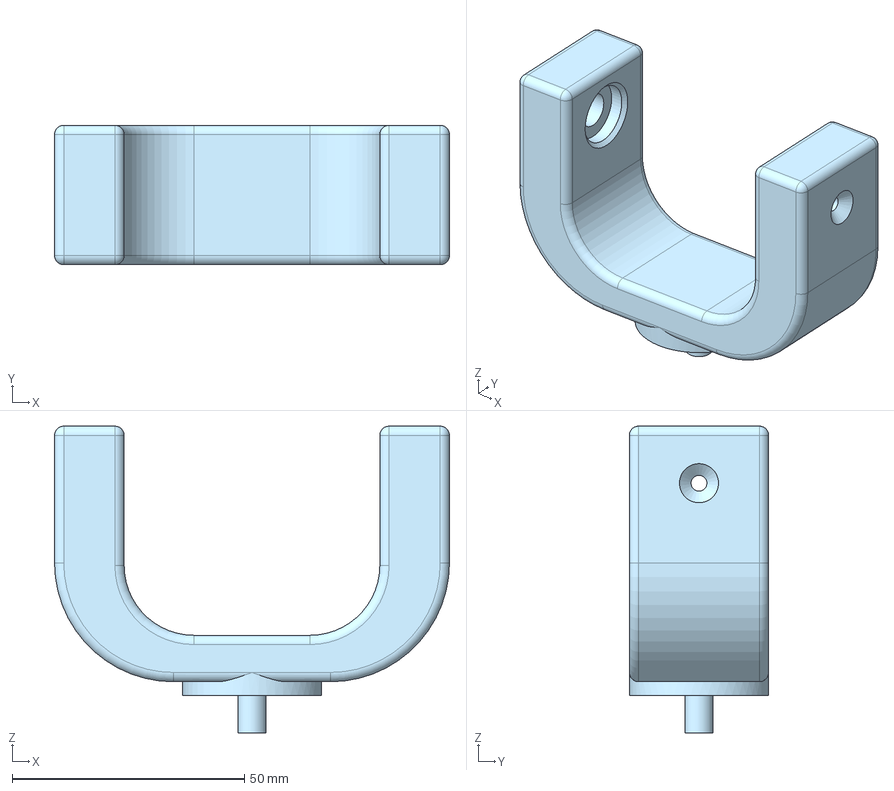
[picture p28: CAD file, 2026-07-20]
cad/models/rotational-base.step
85.0 x 30.0 x 66.0 mm

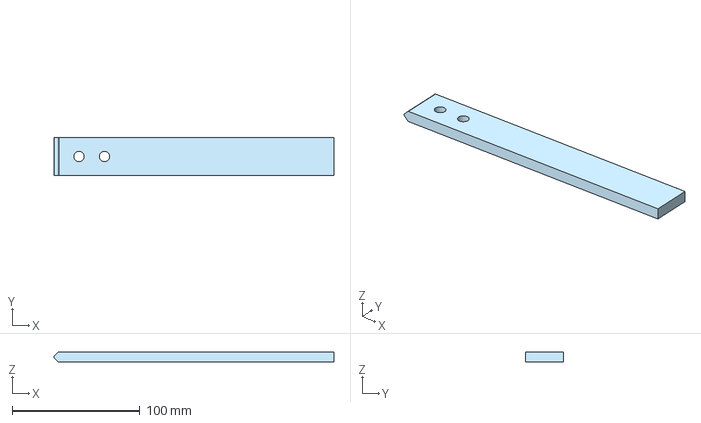
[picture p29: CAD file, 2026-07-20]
cad/models/aluminium-counterweight.step
219.6 x 30.0 x 8.00 mm

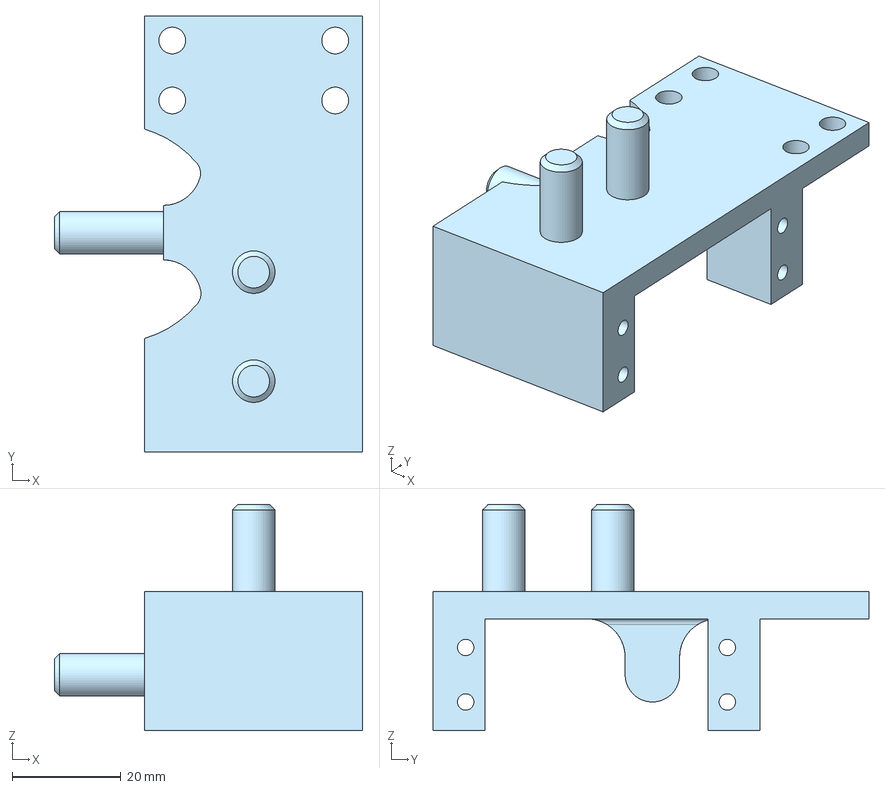
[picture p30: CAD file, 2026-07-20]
cad/models/linear-actuator-mount.step
56.6 x 80.0 x 41.5 mm

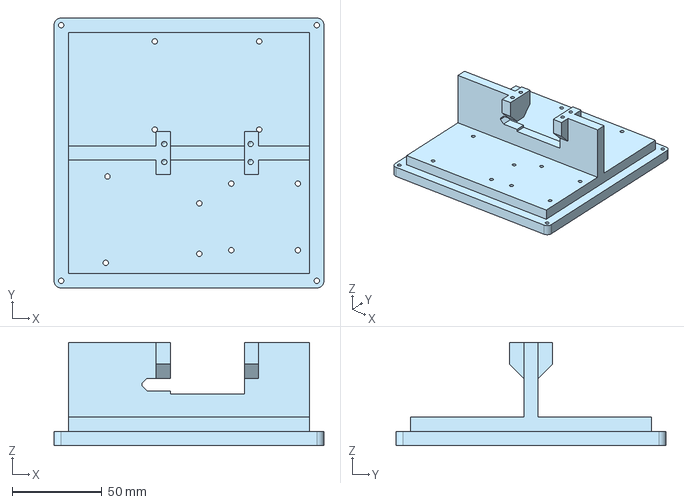
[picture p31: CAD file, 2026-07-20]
cad/models/circuit-box-base.step
150.0 x 150.0 x 57.4 mm

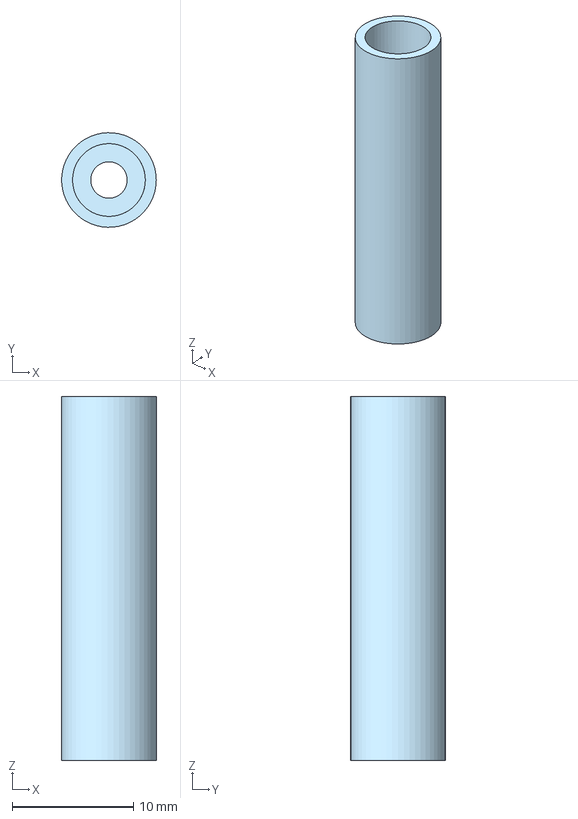
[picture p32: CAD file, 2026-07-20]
cad/models/vertical-shaft.step
7.79 x 7.80 x 30.0 mm

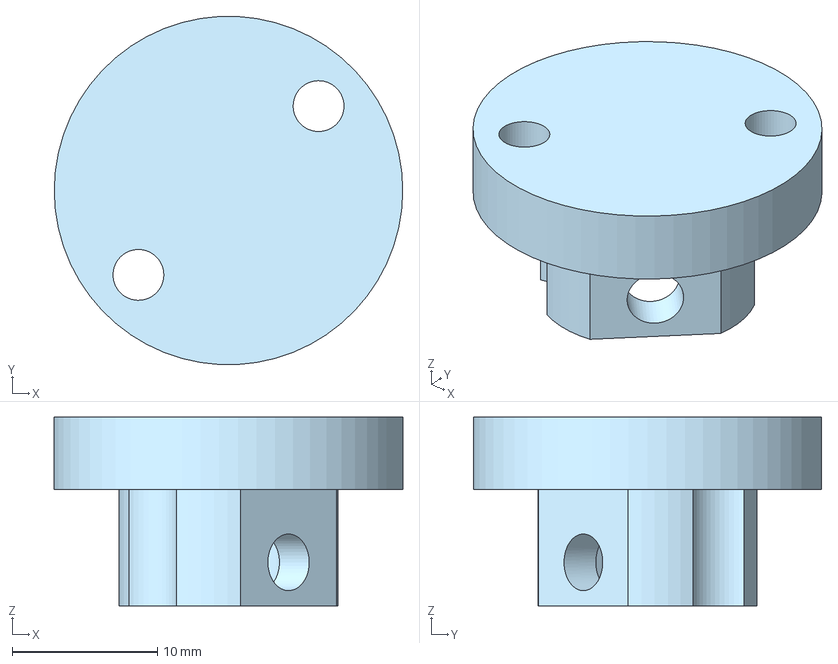
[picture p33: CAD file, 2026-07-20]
cad/models/grip-mechanism-mount.step
24.0 x 24.0 x 13.0 mm

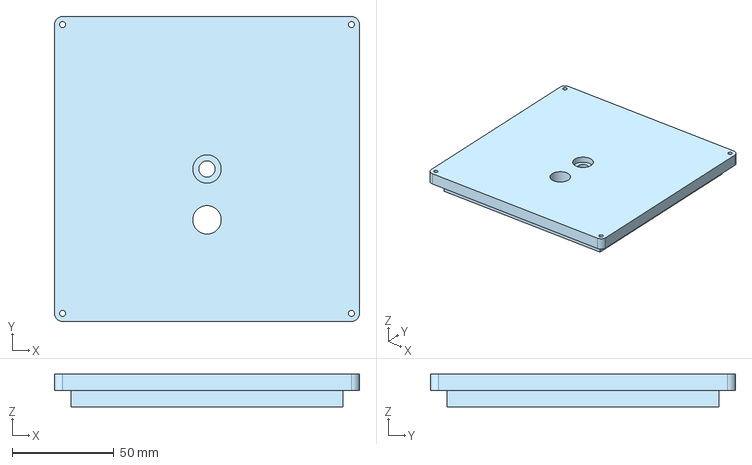
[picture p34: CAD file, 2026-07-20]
cad/models/circuit-box-lid.step
150.0 x 150.0 x 16.0 mm

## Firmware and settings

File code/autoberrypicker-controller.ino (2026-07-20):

#include <Servo.h>

// Pin assignments
const int ROTATION_PIN = 8;
const int ELEVATION_PIN = 10;
const int GRIP_PIN = 9;
const int ACTUATOR_IN1_PIN = 2;
const int ACTUATOR_IN2_PIN = 3;

// Default positions
const int HOME_ROTATION = 90;
const int HOME_ELEVATION = 60;
const int HOME_GRIP = 40;

// Servo objects
Servo rotationServo;
Servo elevationServo;
Servo gripServo;

// Serial input buffer
char buffer[32];
byte bufferIndex = 0;

void setup() {
  Serial.begin(9600);

  pinMode(ACTUATOR_IN1_PIN, OUTPUT);
  pinMode(ACTUATOR_IN2_PIN, OUTPUT);

  Serial.println("Attaching servos...");

  rotationServo.attach(ROTATION_PIN);
  elevationServo.attach(ELEVATION_PIN);
  gripServo.attach(GRIP_PIN);

  Serial.print("Rotation servo attached: ");
  Serial.println(rotationServo.attached());

  Serial.print("Elevation servo attached: ");
  Serial.println(elevationServo.attached());

  Serial.print("Grip servo attached: ");
  Serial.println(gripServo.attached());

  // Move to starting position
  rotationServo.write(HOME_ROTATION);
  elevationServo.write(HOME_ELEVATION);
  gripServo.write(HOME_GRIP);
  delay(1000);

  // Retract actuator on startup
  digitalWrite(ACTUATOR_IN1_PIN, LOW);
  digitalWrite(ACTUATOR_IN2_PIN, HIGH);
  delay(5000);

  digitalWrite(ACTUATOR_IN1_PIN, LOW);
  digitalWrite(ACTUATOR_IN2_PIN, LOW);

  // Prevent rotation servo from holding position when idle
  rotationServo.detach();

  Serial.println("Arduino ready - S:");
}

void loop() {
  while (Serial.available() > 0) {
    char incomingChar = Serial.read();

    if (incomingChar == '\n' || incomingChar == '\r') {
      if (bufferIndex > 0) {
        buffer[bufferIndex] = '\0';
        processCommand();
      }
      bufferIndex = 0;
    } 
    else {
      if (bufferIndex < (sizeof(buffer) - 1)) {
        buffer[bufferIndex++] = incomingChar;
      } 
      else {
        Serial.println("Buffer overflow!");
        bufferIndex = 0;
      }
    }
  }
}

void processCommand() {
  if (bufferIndex == 0) return;

  char component = buffer[0];
  int value = atoi(&buffer[1]);

  switch (component) {

    case 'w':
      elevationServo.write(50);
      Serial.println("Simple elevation UP command");
      break;

    case 's':
      elevationServo.write(30);
      Serial.println("Simple elevation DOWN command");
      break;

    case 'R':
      // Attach rotation servo when needed
      if (!rotationServo.attached()) {
        rotationServo.attach(ROTATION_PIN);
        delay(50);
      }

      rotationServo.write(value);
      break;

    case 'E':
      Serial.print("E command - Buffer: '");
      Serial.print(buffer);
      Serial.print("', Value: ");
      Serial.println(value);

      if (!elevationServo.attached()) {
        Serial.println("Elevation servo detached, reattaching...");
        elevationServo.attach(ELEVATION_PIN);
        delay(50);
      }

      elevationServo.write(value);

      Serial.print("Elevation set to: ");
      Serial.println(value);
      break;

    case 'G':
      gripServo.write(value);
      break;

    case 'K':
      if (rotationServo.attached()) {
        rotationServo.detach();
      }
      break;

    case 'P':
      // Polar command format: P<angle>,<radius>
      char* comma = strchr(buffer, ',');

      if (comma != NULL) {
        *comma = '\0';

        int angle = atoi(&buffer[1]);
        int radius = atoi(comma + 1);

        if (angle >= 0 && angle <= 180 && radius >= 30 && radius <= 90) {

          Serial.print("Polar command - Angle: ");
          Serial.print(angle);
          Serial.print(", Radius: ");
          Serial.println(radius);

          if (!rotationServo.attached()) {
            rotationServo.attach(ROTATION_PIN);
            delay(50);
          }

          rotationServo.write(angle);
          elevationServo.write(radius);

          Serial.print("Rotation: ");
          Serial.print(angle);
          Serial.print(", Elevation: ");
          Serial.println(radius);

        } else {
          Serial.print("Invalid polar values - Angle: ");
          Serial.print(angle);
          Serial.print(", Radius: ");
          Serial.println(radius);
        }

      } else {
        Serial.print("Invalid polar command format: ");
        Serial.println(buffer);
      }

      break;

    case 'A':
      if (value > 0) {
        digitalWrite(ACTUATOR_IN1_PIN, HIGH);
        digitalWrite(ACTUATOR_IN2_PIN, LOW);
      } 
      else if (value < 0) {
        digitalWrite(ACTUATOR_IN1_PIN, LOW);
        digitalWrite(ACTUATOR_IN2_PIN, HIGH);
      } 
      else {
        digitalWrite(ACTUATOR_IN1_PIN, LOW);
        digitalWrite(ACTUATOR_IN2_PIN, LOW);
      }
      break;
  }
}

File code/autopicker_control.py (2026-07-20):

import cv2
import numpy as np
import serial
import time

# Configuration
SERIAL_PORT = 'COM5'
BAUD_RATE = 9600
CAMERA_INDEX = 2
FRAME_WIDTH = 320
FRAME_HEIGHT = 240
FRAME_CENTER_X = FRAME_WIDTH // 2
FRAME_CENTER_Y = FRAME_HEIGHT // 2

# Vision parameters
L_H = 177; U_H = 2
L_S = 120; U_S = 255
L_V = 70; U_V = 255
MIN_CONTOUR_AREA = 500
erode_kernel = np.ones((5, 5), np.uint8)
closing_kernel = np.ones((9, 9), np.uint8)
erode_iterations = 1
dilate_iterations = 2

# Controller tuning
SMOOTHING_FACTOR = 0.7
CENTER_THRESHOLD_PIXELS = 8
P_GAIN_X = 0.04/2; D_GAIN_X = 0.10/2
P_GAIN_Y = 0.03/2; D_GAIN_Y = 0.07/2
MAX_ADJUSTMENT_X = 4.0
MAX_ADJUSTMENT_Y = 1.0
ROTATION_MIN = 0; ROTATION_MAX = 180
ELEVATION_MIN = 0; ELEVATION_MAX = 45

# Pick routine
FRAMES_TO_LOCK = 15
PICK_OFFSET_DEGREES = -35
ACTUATOR_EXTEND_TIME = 3
GRIP_OPEN = 40
GRIP_CLOSED = 180
DROPOFF_ROTATION = 170
DROPOFF_ELEVATION = 20

# Send a command to the Arduino
def send_command(ser, cmd):
    print(f"Sending: {cmd}")
    ser.write(f"{cmd}\n".encode())

# Pick routine
def execute_pick_routine(ser, final_rotation, final_elevation):
    print("\n--- LOCKED ON: EXECUTING PICK ROUTINE ---")

    pick_elevation = final_elevation + PICK_OFFSET_DEGREES
    pick_elevation = max(ELEVATION_MIN, min(ELEVATION_MAX, pick_elevation))

    send_command(ser, f"E{int(pick_elevation)}")
    time.sleep(1.0)

    send_command(ser, "A1")
    time.sleep(ACTUATOR_EXTEND_TIME)
    send_command(ser, "A0")

    send_command(ser, f"G{GRIP_CLOSED}")
    time.sleep(1.0)

    send_command(ser, "A-1")
    time.sleep(ACTUATOR_EXTEND_TIME)
    send_command(ser, "A0")

    send_command(ser, f"G{GRIP_OPEN}")
    time.sleep(1.0)

    print("--- PICK ROUTINE COMPLETE ---\n")

# Initialisation
try:
    arduino = serial.Serial(SERIAL_PORT, BAUD_RATE, timeout=2)
    time.sleep(2)
    print("Arduino connection established.")
except serial.SerialException as e:
    exit(f"FATAL: Could not connect to Arduino. {e}")

cap = cv2.VideoCapture(CAMERA_INDEX, cv2.CAP_DSHOW)
cap.set(cv2.CAP_PROP_FRAME_WIDTH, FRAME_WIDTH)
cap.set(cv2.CAP_PROP_FRAME_HEIGHT, FRAME_HEIGHT)

if not cap.isOpened():
    exit("FATAL: Could not open camera.")

# Main loop
current_rotation = 90
current_elevation = 15
previous_error_x = 0
previous_error_y = 0
smoothed_x = FRAME_CENTER_X
smoothed_y = FRAME_CENTER_Y
frame_counter = 0
COMMAND_INTERVAL = 2
STATE = "SEARCHING"
lock_on_counter = 0

while True:
    ret, frame = cap.read()
    if not ret:
        break

    if STATE == "SEARCHING" or STATE == "LOCKING":
        frame_counter += 1

        hsv = cv2.cvtColor(frame, cv2.COLOR_BGR2HSV)

        lower1 = np.array([L_H, L_S, L_V])
        upper1 = np.array([179, U_S, U_V])
        lower2 = np.array([0, L_S, L_V])
        upper2 = np.array([U_H, U_S, U_V])

        mask1 = cv2.inRange(hsv, lower1, upper1)
        mask2 = cv2.inRange(hsv, lower2, upper2)
        mask = cv2.bitwise_or(mask1, mask2)

        mask = cv2.morphologyEx(mask, cv2.MORPH_CLOSE, closing_kernel)
        mask = cv2.erode(mask, erode_kernel, iterations=erode_iterations)
        mask = cv2.dilate(mask, erode_kernel, iterations=dilate_iterations)

        contours, _ = cv2.findContours(mask, cv2.RETR_EXTERNAL, cv2.CHAIN_APPROX_SIMPLE)

        best_contour = None
        if contours:
            best_contour = max(contours, key=cv2.contourArea)
            if cv2.contourArea(best_contour) < MIN_CONTOUR_AREA:
                best_contour = None

        if best_contour is not None:
            STATE = "LOCKING"

            ((x, y), radius) = cv2.minEnclosingCircle(best_contour)
            center_x = int(x)
            center_y = int(y)

            smoothed_x = SMOOTHING_FACTOR * center_x + (1 - SMOOTHING_FACTOR) * smoothed_x
            smoothed_y = SMOOTHING_FACTOR * center_y + (1 - SMOOTHING_FACTOR) * smoothed_y

            error_x = smoothed_x - FRAME_CENTER_X
            error_y = FRAME_CENTER_Y - smoothed_y

            if abs(error_x) > CENTER_THRESHOLD_PIXELS or abs(error_y) > CENTER_THRESHOLD_PIXELS:
                lock_on_counter = 0

                proportional_x = P_GAIN_X * error_x
                derivative_x = D_GAIN_X * (error_x - previous_error_x)
                adjustment_x = proportional_x + derivative_x

                proportional_y = P_GAIN_Y * error_y
                derivative_y = D_GAIN_Y * (error_y - previous_error_y)
                adjustment_y = proportional_y + derivative_y

                adjustment_x = max(-MAX_ADJUSTMENT_X, min(MAX_ADJUSTMENT_X, adjustment_x))
                adjustment_y = max(-MAX_ADJUSTMENT_Y, min(MAX_ADJUSTMENT_Y, adjustment_y))

                current_rotation -= adjustment_x
                current_elevation -= adjustment_y

                current_rotation = max(ROTATION_MIN, min(ROTATION_MAX, current_rotation))
                current_elevation = max(ELEVATION_MIN, min(ELEVATION_MAX, current_elevation))

                if frame_counter % COMMAND_INTERVAL == 0:
                    send_command(arduino, f"R{int(current_rotation)}")
                    send_command(arduino, f"E{int(current_elevation)}")

            else:
                lock_on_counter += 1

            previous_error_x = error_x
            previous_error_y = error_y

            cv2.circle(frame, (int(smoothed_x), int(smoothed_y)), 7, (0, 255, 0), -1)

        else:
            STATE = "SEARCHING"
            lock_on_counter = 0
            previous_error_x = 0
            previous_error_y = 0

        if lock_on_counter >= FRAMES_TO_LOCK:
            STATE = "PICKING"
            execute_pick_routine(arduino, current_rotation, current_elevation)
            STATE = "SEARCHING"
            lock_on_counter = 0
            current_rotation = 90
            current_elevation = 15

    dz_top_left = (
        FRAME_CENTER_X - CENTER_THRESHOLD_PIXELS,
        FRAME_CENTER_Y - CENTER_THRESHOLD_PIXELS,
    )
    dz_bottom_right = (
        FRAME_CENTER_X + CENTER_THRESHOLD_PIXELS,
        FRAME_CENTER_Y + CENTER_THRESHOLD_PIXELS,
    )

    cv2.rectangle(frame, dz_top_left, dz_bottom_right, (0, 255, 255), 1)

    status_text = f"State: {STATE} | Lock: {lock_on_counter}/{FRAMES_TO_LOCK}"
    cv2.putText(frame, status_text, (5, 20),
                cv2.FONT_HERSHEY_SIMPLEX, 0.5, (0, 255, 255), 1)

    cv2.imshow("Camera Feed", frame)

    if cv2.waitKey(1) & 0xFF == ord('q'):
        break

# Cleanup
print("Exiting and moving to safe position...")

send_command(arduino, "R90")
send_command(arduino, "E15")

time.sleep(2)

cap.release()
cv2.destroyAllWindows()
arduino.close()
